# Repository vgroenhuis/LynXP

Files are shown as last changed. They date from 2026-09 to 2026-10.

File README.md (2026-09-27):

# LynXP

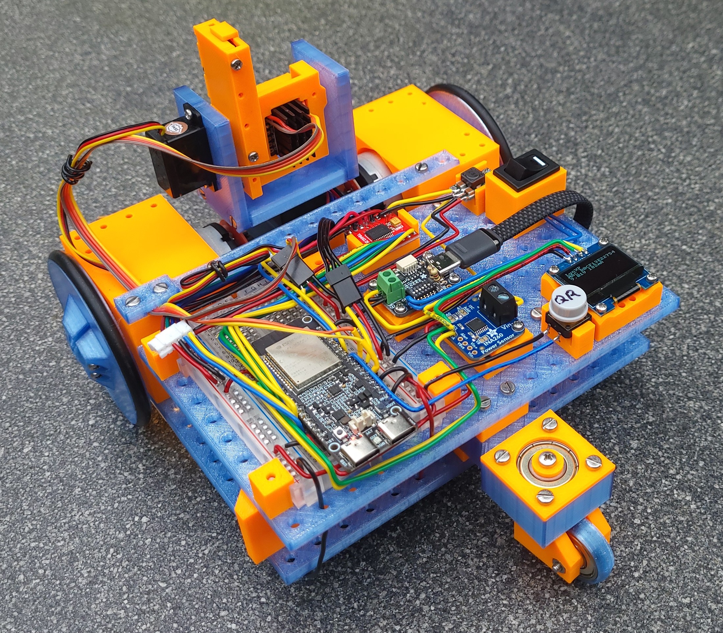
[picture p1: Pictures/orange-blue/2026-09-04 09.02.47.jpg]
LynXP


LynXP is a wheeled robot with pan-tilt camera and web-based control interface, through which minigames can be played. It is based on the SmartXP robot used in Creative Technology curriculum at University of Twente, hence the -XP in the name.

## Electronics

The power and control circuit (powerbank, USB power delivery trigger, current sensor, buck converter, ESP32-C5, ESP32-S3-Sense camera, motor driver, servos, motors, OLED, and status LED):

Power and control circuit diagram

Also available as [PDF](Schematic/powerbank_circuit.pdf) or [PNG](Schematic/powerbank_circuit.png).

A single PCB replacing the breadboard and modules is planned; see the [PCB requirements](Schematic/PCB_requirements.md).

## Bill of Materials

| Component | Part | Qty | Cost (each) | Supplier | Notes |
|---|---|---|---|---|---|
| Powerbank | Anker Zolo 10.000 mAh | 1 | €35 | [Anker](https://www.anker.com/products/a1688) / [GSMNetShop](https://gsmnetshop.nl/products/externe-batterij-anker-zolo-10000mah-30w-qc-plus-pd-1-x-usb-a-2-x-usb-c-zwart-a1688h11) / [DeBatterijPro](https://www.debatterijpro.nl/nl/product/anker-zolo-powerbank-10000mah-30w-qc-pluspd-met-usb-c-kabel-zwart.html) | Dimensions 110x65.5x25 mm. A different powerbank is possible; use the [CAD_Generators wall generator](https://github.com/vgroenhuis/CAD_Generators) to create a holder for other dimensions. |
| Drive motor | TT Motor GM37-520TB-1250-30-EN (12V, 30:1 transmission) | 2 | €10 | [Alibaba](https://www.alibaba.com/product-detail/TT-Motor-High-Torque-37mm-GM37_1601884925507.html) / [Aliexpress](https://nl.aliexpress.com/item/1005007677802607.html) / [Funduinoshop](https://funduinoshop.com/nl/doe-het-zelf-workshop/kits/chassis/jgb37-520-encoder-tandwielmotor-kit-12v-12rpm-met-wiel) / [TTmotor](https://www.ttmotor.com/high-torque-dc-gear-motor-589121520253040455580100120160750rpm-product/) | GM37 is a quite common geared DC motor size, but it is hard to find one in EU with encoder attached. |
| Camera module | Seeed XIAO ESP32S3 Sense | 1 | €16 | [Seeed Studio](https://www.seeedstudio.com/XIAO-ESP32S3-Sense-p-5639.html) / [TinyTronics](https://www.tinytronics.nl/en/development-boards/microcontroller-boards/with-wi-fi/seeed-studio-xiao-esp32-s3-sense) / [Reichelt](https://www.reichelt.com/nl/nl/shop/product/xiao_esp32s3_sense_wifi_bt_camera_ov3660_zonder_header-358353) |  |
| Main MCU | ESP32-C5-WIFI6-KIT-N16R8-M | 1 | €12 | [Aliexpress](https://nl.aliexpress.com/item/1005012275503208.html) | Compatible with ESP32-C5-DevkitC-1 from Espressif |
| USB-PD trigger board | HUSB238 | 1 | €11 | [Adafruit](https://www.adafruit.com/product/5991) / [Kiwi-electronics](https://www.kiwi-electronics.com/en/adafruit-usb-type-c-power-delivery-dummy-i2c-or-switchable-husb238-20162) | |
| Current sensor | INA260 | 1 | €11 | [Adafruit](https://www.adafruit.com/product/4226) / [Kiwi-electronics](https://www.kiwi-electronics.com/nl/adafruit-ina260-high-or-low-side-voltage-current-power-sensor-4222)  | Optional |
| Pan servo | MG996R 180° | 1 | €7 | [Bits&Parts](https://www.bitsandparts.nl/servo-motor-digitaal-mg996r-high-torque-metal-gears-p1922620) / [TinyTronics](https://www.tinytronics.nl/en/mechanics-and-actuators/motors/servomotors/mg996r-servo) / [Otronic](https://www.otronic.nl/nl/servo-mg996r-180-graden.html)  | LynXP One has SRT DL3020, which is overkill |
| OLED display | SSD1306, 128x64, 1.3" | 1 | €7 | [TinyTronics](https://www.tinytronics.nl/en/displays/oled/1.3-inch-oled-display-128*64-pixels-white-i2c) | LynXP One has 0.96", but this is too small |
| nOOds flexible LED | 30 cm | 1 | €5 | [Adafruit](https://www.adafruit.com/product/5509) / [Kiwi-electronics](https://www.kiwi-electronics.com/en/leds-114/other-leds-360/noods-flexible-led-filament-3v-300mm-long-warm-white-11360)  | Optional |
| Breadboard | EIC premium 400 points | 1 | €4 | [Tinytronics](https://www.tinytronics.nl/en/tools-and-mounting/prototyping-supplies/breadboards/eic-premium-breadboard-400-points-transparent) | |
| Motor driver | TB6612FNG | 1 | €3 | [Otronic](https://www.otronic.nl/nl/motor-driver-module-tb6612fng-voor-arduino.html) | |
| Tilt servo | SG90 180° | 1 | €3 | [Bits&Parts](https://www.bitsandparts.nl/servo-motor-analoog-micro-servo-9g-sg90-180%C2%B0-p1907205) / [TinyTronics](https://www.tinytronics.nl/en/mechanics-and-actuators/motors/servomotors/sg90-mini-servo) / [Otronics](https://www.otronic.nl/nl/servo-sg90-micro-180-graden.html) | Or MG90S. (LynXP One has Hitec HS-53) |
| Bearing | 608ZZ | 3 | €1 | [123-3D](https://www.123-3d.nl/123-3D-Kogellager-608ZZ-10-stuks-i1406.html) | For caster |
| Buck converter | OT253-B47 | 1 | €2 | [Otronic](https://www.otronic.nl/en/step-down-buck-converter-from-45v-24v-to-5v-3a-4r.html) | |
| O-ring | 60x5 mm | 2 | €1 | [Lagerkoning](https://www.lagerkoning.nl/o-ring-60x5mm-nbr-70.html) / [O-ring-stocks](https://www.o-ring-stocks.eu/nl/o-ring-60x5-nbr-nitril-70-shore-a-zwart-ors2856) | Inner diameter 60 mm, thickness 5 mm. Used as tyres for wheels. When mounted on rim, effective outer diameter is 71.5 mm. |
| On/off switch | 12x19 mm | 1 | €1 | [Tinytronics](https://www.tinytronics.nl/en/switches/manual-switches/rocker-switches/standaard-built-in-rocker-switch-small) | Optional; SPDT is better because switch closed = off |
| Pushbutton | 12 mm | 1 | €1 | [Kiwi-electronics](https://www.tinytronics.nl/en/switches/manual-switches/rocker-switches/standaard-built-in-rocker-switch-normal) | To show QR code on OLED; toggle switch also possible |
| **Total** | | | **€143** | | |

Total price excludes shipping costs, filament, wires, screws, resistors.

## CAD

Solidworks source files and STEP exports are available in [CAD/LynXP One Sept 2026](<CAD/LynXP One Sept 2026>):
- [Solidworks](<CAD/LynXP One Sept 2026/Solidworks>): native parts (`.SLDPRT`) and assemblies (`.SLDASM`), including [CompleteAssembly.SLDASM](<CAD/LynXP One Sept 2026/Solidworks/CompleteAssembly.SLDASM>)
- [STEP](<CAD/LynXP One Sept 2026/STEP>): neutral format for slicing and viewable in any CAD tool, including the [full robot assembly](<CAD/LynXP One Sept 2026/STEP/Full robot assembled/CompleteAssembly.STEP>)

The powerbank holder walls can be regenerated for different powerbank dimensions using [CAD_Generators](https://github.com/vgroenhuis/CAD_Generators).

## Assembly

Will be added later.

## Photos

More photos:
- [LynXP One](Pictures/orange-blue)
- [Older iterations](Pictures/older%20iterations)

## AI disclaimer
Claude was used to help developing software and circuit diagrams. No AI tools were used for hardware development.

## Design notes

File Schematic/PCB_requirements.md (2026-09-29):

# LynXP main PCB — requirements

This document lists the requirements for a single main PCB that replaces the breadboard, the
breakout modules and the wiring of LynXP One (see [powerbank_circuit.png](powerbank_circuit.png)
and the [BOM in the README](../README.md#bill-of-materials)). As many functions as practical
should be on the PCB itself instead of on plug-in modules.

Key words: **must** = hard requirement, **should** = strongly preferred, **may** = optional/nice to have.
Items marked *(verify)* are facts the designer must check against the current datasheet before
committing to the layout.

---

## 1. Scope: what moves onto the PCB

| Function | LynXP One (breadboard) | PCB |
|---|---|---|
| Main MCU | Waveshare ESP32-C5-WIFI6-KIT devkit | **ESP32-C5-WROOM-1U** module soldered on the PCB |
| USB-PD trigger | Adafruit HUSB238 breakout | **HUSB238** chip + USB-C receptacle on the PCB |
| Current/voltage sensor | Adafruit INA260 breakout | **INA260** chip on the PCB |
| 5 V buck converter | OT253-B47 module | Buck converter on the PCB |
| 3.3 V supply | Devkit LDO | Regulator on the PCB |
| Motor driver | TB6612FNG module | **TB6612FNG** chip on the PCB |
| Servo PWM | ESP32 LEDC | **PCA9685** 16-channel PWM driver (motor PWM stays on ESP32 LEDC) |
| Extra GPIO | — | **MCP23017** 16-bit I/O expander |
| Analog inputs | — | **8-channel I²C ADC** for add-on sensors (new, see §5.2) |
| Programming | Devkit USB | One USB-C port to the ESP32-C5 native USB (no USB-UART chip) |
| Camera (XIAO ESP32-S3 Sense) | Loose jumper wires | Keyed connector for a 4-wire flat cable |
| OLED display | 1.3" 128×64 I²C module on jumper wires | **1.3" 128×64 OLED integrated on the PCB** (strongly recommended; 4-pin header acceptable, see §5.1) |
| nOOds LED, buttons, power switch | Loose wires | Connectors / on-board parts |
| Headlights | — | Two headlight outputs with connectors (new, see §11.1) |
| Microphone, speaker | — | **Optional**: on-board I²S microphone and speaker amplifier (new, see §11.2) |

Stays off-board: powerbank, motors, servos, XIAO ESP32-S3 Sense camera, nOOds LED, headlights, optional speaker/mic.

---

## 2. Power input: USB-PD (HUSB238)

### 2.1 Negotiation
- **Must** have a USB-C receptacle (power only; CC1, CC2, VBUS, GND) for the powerbank; its VBUS net is named
  **VBUS_PD**. The connector is labelled
  **"POWER"** on the silkscreen, clearly different from the programming port.
- **Must** use the HUSB238 as PD sink controller. Default request: **12 V** (the GM37 motors are
  12 V motors; LynXP One ran them at 9 V).
- **Should** allow selecting the requested voltage (at least 9 V and 12 V; 5/15/20 V a bonus) with
  solder jumpers or a DIP switch on the HUSB238 voltage-select resistor network *(verify resistor
  values in the HUSB238 datasheet)*. The ISET/current resistor (10.5 kΩ on LynXP One) must also be
  on the board.
- **Must** connect the HUSB238 I²C (address 0x08) to the main I²C bus so firmware can read the
  contract and optionally request another PDO.
- The negotiated voltage is distributed as rail **V_BUS** (12 V by default). Its voltage depends on
  the selected/negotiated PDO (e.g. 9 V if the powerbank cannot deliver 12 V, or 15 V if selected).
  Everything on V_BUS must therefore work from 5 V up to 20 V.

### 2.2 On/off switch that wakes the powerbank (important)
Many powerbanks (including the Anker Zolo) switch their output off after a period of low current,
and only turn it on again when they detect a *new* attach event on the CC lines. Pulling and
re-inserting the cable works; switching the load does not.

- **Must**: the main on/off switch breaks the **CC1 and CC2** lines between the USB-C receptacle and
  the HUSB238 (one pole per CC line). Switching OFF looks like a cable unplug to the powerbank (it
  removes VBUS_PD itself); switching ON is a fresh attach, which wakes the powerbank.
- **Must**: the same switch also puts the **PD controller to sleep when OFF and wakes it when ON**,
  so that every switch-on starts the PD controller from its initial state and it renegotiates the
  contract, instead of keeping stale state alive on residual VBUS_PD/bulk-capacitor charge or on
  voltage back-fed from the programming USB port. Implement with an extra pole on the main switch,
  e.g. driving the PD controller's enable/sleep pin, or cutting its supply combined with a VBUS_PD
  discharge path so it gets a clean power-on reset *(verify which mechanism the HUSB238 supports;
  a comparable PD sink controller with a proper enable pin is acceptable if the HUSB238 has none)*.
- The main switch is therefore a multi-pole switch (e.g. 3PDT/4PDT slide or toggle). There must be
  only this one power switch for the PD input; no separate wake/sleep buttons.
  - Side effect: the switch carries only CC signal current, so no high-current switch is needed.
  - Keep CC traces short, place the switch close to the receptacle and the HUSB238. The switch
    must be a real mechanical switch, large and easy to reach from outside the robot (panel or
    edge mount, or wired to an off-board panel switch via a small connector with a footprint for
    an on-board switch as well).
- **Should** use another pole of the same main switch to also open the PD output load switch,
  so the output is guaranteed off even with a non-compliant source.
- Note: the powerbank must be connected with a **USB-C to USB-C** cable. A USB-A to C cable has
  no CC handshake and cannot be woken or switched this way.

### 2.3 Inrush and capacitance
- USB-C limits sink bulk capacitance on VBUS_PD before a contract is established (≤10 µF *(verify)*).
  Large bulk capacitors (motor/servo rails) **must** sit behind a load switch/PMOS that only closes
  once the HUSB238 reports a valid contract (as the Adafruit breakout does), with soft-start.

### 2.4 Protection
- **Must**: TVS diode on VBUS_PD rated for the maximum selectable PD voltage (≥ 20 V standoff if 20 V
  can be selected).
- No fuse on the PCB: overcurrent protection is provided by the powerbank, which cuts its output
  when the negotiated current (~2.5–3 A at 12 V for a 30 W powerbank) is exceeded.

### 2.5 Current sensing (INA260)
- **Must** place an INA260 (integrated shunt, high-side) in series with V_BUS directly after
  the PD output switch, so it measures the complete robot consumption.
- I²C address: **0x40** (firmware `INA260_I2C_ADDR`), A0 and A1 hardwired to GND.
- ALERT pin left unconnected.

---

## 3. Power rails

| Rail | Source | Minimum rating | Notes |
|---|---|---|---|
| **V_BUS** (12 V default; VBUS_PD after PD load switch and INA260) | HUSB238 | 3 A | Motors (TB6612 VM), buck inputs, exposed |
| **5 V** logic | Buck from V_BUS | 3 A | Camera, nOOds, exposed |
| **V_SERVO** (5 V default) | Separate buck from V_BUS | 3 A | 8 servo headers |
| **3.3 V** | Regulator from 5 V | 1 A | ESP32-C5, MCP23017, PCA9685, INA260, HUSB238 I/O, encoders |

- Net names: **VBUS_PD** = raw VBUS pin of the POWER connector; **VBUS_PROG** = raw VBUS pin of
  the PROG connector; **V_BUS** = main rail (VBUS_PD after load switch and INA260). Bare
  "VBUS" is not used as a net name.
- Bucks **must** accept 5–20 V input with margin (≥ 28 V abs. max) because the rail follows the PD
  voltage.
- Servos **should** get their own buck, separate from logic 5 V, so servo stall currents
  (MG996R ~2.5 A stall) cannot brown out the ESP32. Bulk capacitance on V_SERVO (≥ 470–1000 µF,
  low-ESR).
- 3.3 V regulator must handle ESP32-C5 Wi-Fi peaks (≥ 500 mA peak for the module alone); an LDO
  from 5 V with ≥ 1 A rating or a small buck.
- When only the programming USB port is connected, the 5 V/3.3 V logic **must** run from **VBUS_PROG** (the
  programming port's VBUS)
  through an ORing diode / ideal diode, without back-feeding into the buck output or the PD side.
  V_SERVO and V_BUS stay unpowered in that case.
- **Must**: power-good LED on each rail (V_BUS, 5 V, V_SERVO, 3.3 V).
- **Should**: test points on every rail and GND.

### 3.1 Exposed power
- **Must** expose **all rails — V_BUS, V_SERVO, 5 V, 3.3 V — and GND**, so they can feed
  additional external components, both on:
  - **screw terminals** (5.0 mm or 3.5 mm pitch, one terminal per rail + at least two GND), and
  - **2.54 mm female headers** (several pins per rail, e.g. a 2×N or 4×1 block per rail).
- Silkscreen voltage next to every pin. Use distinct connector colours or clear markings to avoid
  plugging a 3.3 V device into V_BUS. Silkscreen names V_BUS and V_SERVO with their
  default voltage (e.g. "V_BUS (12 V)").

---

## 4. Main MCU: ESP32-C5-WROOM-1U

- **Must** use ESP32-C5-**WROOM-1U**, the variant with an antenna connector (U.FL/IPEX) for an
  external antenna. The WROOM-1 variant with PCB antenna is not acceptable. A variant **with PSRAM is required**
  (current devkit is N16R8); choose flash/PSRAM size to match the firmware partition table
  ([partitions.csv](../Firmware/Robot_ESP32_C5_IDF/partitions.csv)) *(verify availability)*.
- **Must** route the U.FL cable to an external antenna mounting point away from motors, the metal
  frame and the powerbank; keep the module away from the buck converters and motor traces.
  A 2.4/5 GHz dual-band external antenna with U.FL cable is part of the BOM.
- **Must**: EN reset button, BOOT button on GPIO28, EN RC delay
  (10 kΩ / 1 µF), decoupling per module datasheet.
- Reserved pins (from [board_pins.hpp](../Firmware/Robot_ESP32_C5_IDF/main/board_pins.hpp)):
  GPIO13/14 = USB D−/D+, GPIO16–22 = flash/PSRAM, **GPIO15 cannot be used** (PSRAM).
- Strapping: **GPIO28 must not be externally driven** — only the BOOT button may pull it low. It
  may only connect to inputs (as the camera UART RX line in the pin map below). The other
  strapping pins need no special care.

### 4.1 Programming port
- **Must**: exactly one USB-C receptacle, labelled **"PROG"**, wired to the ESP32-C5 native
  USB-Serial/JTAG (GPIO13/14). No USB-UART converter chip. 5.1 kΩ Rd on its own CC1/CC2, ESD
  protection on D+/D− (e.g. USBLC6-2), 90 Ω differential routing.
- **Must**: a 2.54 mm UART0 header for an external USB-UART adapter: GND, U0TXD, U0RXD
  (GPIO11/GPIO12 *(verify)*), plus EN and BOOT so an adapter can also flash the module. 3.3 V pin
  via solder jumper, open by default.

### 4.2 Suggested pin map
Pan/tilt servos move to the PCA9685 and motor direction pins to the MCP23017 (see §6, §7). Motor
PWM stays on native ESP32 pins (LEDC, 20–30 kHz, inaudible) on the same GPIOs as now; the remaining ESP32 pins keep the bench-verified LynXP One assignment. The designer may
reassign pins; any change must be documented so `board_pins.hpp` can be updated.

| Function | Connection |
|---|---|
| Motor PWMA (right) / PWMB (left) | 9 / 0 (LEDC; pull-downs so motors are off until firmware runs) |
| Motor AIN1, AIN2 (right) / BIN1, BIN2 (left) | MCP23017 GPA0, GPA1 / GPA2, GPA3 |
| Pan / tilt servo | PCA9685 channel 0 / 1 |
| Encoder left A, B | 26, 25 |
| Encoder right A, B | 24, 23 |
| I²C SDA / SCL | 2 / 3 |
| Camera UART RX / TX | 4 / 28 |
| Screen-select potentiometer (§5.1) | GPIO1 (ADC1_CH0) |
| UART0 TX / RX | 11 / 12 *(verify)* |
| I²S BCLK / WS (optional microphone and amplifier, §11.2) | 5 / 6 |
| I²S DIN (microphone) / DOUT (amplifier) | 8 / 10 |
| Addressable status LED + RGB LED strip header (§11) | 7 |

Any GPIOs left over (e.g. GPIO27, formerly the QR button) go to a 2.54 mm female header.

Encoders **must** stay on native GPIOs (PCNT peripheral).

---

## 5. I²C bus

- One 3.3 V I²C bus shared by all devices, running at 400 kHz.
- **Must**: external SDA/SCL pull-up resistors to 3.3 V, populated by default (0805, e.g. 2.2 kΩ;
  value chosen for the total bus capacitance at 400 kHz). The ESP32-C5's internal pull-ups are not
  relied on.
- Address map (must be conflict-free — note the PCA9685 default **0x40 clashes with the INA260**):

| Device | Address |
|---|---|
| HUSB238 | 0x08 (fixed) |
| MCP23017 | 0x20 (A0–A2 solder jumpers) |
| OLED (SH1106/SSD1306-compatible) | 0x3C (0x3D via solder jumper) |
| INA260 | 0x40 (A0, A1 to GND) |
| PCA9685 | **0x41** (A0 to 3.3 V, A1–A5 to GND); its All-Call address 0x70 is also in use |
| 8-channel ADC (§5.2) | 0x48 (address pins to GND) |
| Board-ID EEPROM (§12.1) | 0x50 |

- **Should**: one or two Qwiic/STEMMA QT (JST-SH 4-pin, 3.3 V) connectors plus a 2.54 mm I²C
  header for add-ons.

### 5.1 On-board 1.3" OLED display
- **Strongly recommended**: the 1.3" 128×64 monochrome OLED is integrated on the PCB. Use a bare
  1.3" OLED glass panel with integrated controller and FPC tail (typically 30-pin, soldered or in
  an FPC connector), with all support circuitry on the PCB. Panel colour white (as on LynXP One);
  blue or yellow acceptable.
- Controller: the current firmware uses the SSD1306 driver with a 2-column offset
  (`CONFIG_OFFSETX=2` in [sdkconfig.defaults](../Firmware/Robot_ESP32_C5_IDF/sdkconfig.defaults)),
  i.e. the LynXP One module is effectively an **SH1106** (132-column RAM). An SH1106 panel is
  preferred so firmware stays unchanged; an SSD1306/SSD1309 panel is acceptable if documented.
  *(verify controller of the chosen panel)*
- Interface: **I²C** on the shared bus, address 0x3C (0x3D selectable). Interface-select pins
  (BS0–BS2) strapped for I²C, D1/D2 joined for SDA as the panel datasheet specifies.
- Supply: logic from 3.3 V. The OLED drive voltage (VCC/VPP, typically 7–15 V) must be generated
  as required by the controller: internal charge pump with its flying capacitors (SH1106/SSD1306),
  or a small external boost converter if the panel needs external VCC (e.g. SSD1309). Include
  IREF resistor, VCOMH/VCC decoupling and all other passives from the panel's reference circuit.
- RES# (reset) connected to an MCP23017 output or ESP32 GPIO with RC fallback, so firmware can
  reset a hung display.
- **Should**: the display power can be switched off (load switch or controller sleep is enough).
- Mechanical: the panel **must** be on the top side, fully visible with the robot assembled,
  readable in the orientation the robot is normally viewed from (text upright). Provide a cut-out
  or keep-out under the FPC bend, and a mounting method for the glass (double-sided foam tape
  area and/or a 3D-printed bezel with M2/M2.5 holes; include the bezel in the STEP deliverable).
  Keep tall components and connectors away from the panel so it is not damaged or shadowed.
- **Must**: a **potentiometer with turn knob directly right of the OLED**, used to select the screen
  shown. PCB-mount rotary
  potentiometer with shaft (e.g. 9 mm type, linear, 10 kΩ) and a knob large enough to turn by
  hand, between 3.3 V and GND, wiper to a native ESP32-C5 ADC pin with a 100 nF filter capacitor.
  The knob must be reachable with the robot assembled and not obstruct the view of the display.
- **Acceptable alternative** (only if integrating the panel is not feasible): a 4-pin 2.54 mm
  female header on the same I²C bus for a 1.3" OLED module, placed and with mounting holes so the
  module sits in the same position (display visible, potentiometer right of it). Note that the
  order of the 4 pins differs per manufacturer (e.g. GND-VCC-SCL-SDA vs VCC-GND-SCL-SDA), so the
  header needs solder jumpers for both common orders — one reason integration is strongly
  preferred. The on-panel requirements above (controller, charge pump, RES#) then do not apply.

### 5.2 8-channel ADC for analog sensors
Lets students add analog sensors (potentiometers, light sensors, IR distance sensors, line
sensors, etc.) without using ESP32 pins.
- **Must**: an 8-channel I²C ADC on the shared bus, ≥ 10-bit, e.g. **ADS7828** (12-bit, 8
  single-ended inputs, I²C 0x48–0x4B) or an equivalent available at JLCPCB/LCSC. Powered from 3.3 V;
  input range 0–3.3 V (reference = 3.3 V supply, or internal reference if the chosen part has a
  better one — document which).
- **Must**: **8 sensor connectors**, one per channel: 3-pin 2.54 mm male headers in the order
  **GND, 3.3 V, signal** (same style as the servo headers, so standard 3-wire sensor cables fit),
  labelled **A0–A7**, each with label space for the sensor name.
- Supply on these headers is 3.3 V only, so sensor outputs stay within the ADC range. No 5 V
  option; users with 5 V-only sensors add their own level shifting.
- Input protection per channel: series resistor (~1 kΩ) and clamping to 3.3 V/GND, plus footprints
  (unpopulated by default) for a pull-down resistor and an RC filter capacitor.

---

## 6. PCA9685 PWM driver: servos, headlights, LEDs

- **Must**: PCA9685 powered from 3.3 V (3.3 V signal levels are fine for hobby servos).
- **Must**: OE pin pulled **high** (outputs disabled) by default and controlled by MCP23017 **GPA7**
  (output-only pin; floats at reset so the pull-up keeps OE high), so servos receive no pulses
  until firmware has initialised them. This also prevents
  the random boot-time pan rotation seen on LynXP One.
- All 16 PCA9685 channels share one PWM frequency (~50 Hz for servos; the PCA9685 cannot exceed
  ~1.5 kHz), which is why motor PWM is not on the PCA9685.
- **Must**: **8 servo headers**, standard 3-pin 2.54 mm male (GND, V_SERVO, signal — in that
  order, with polarity marked on silkscreen), on PCA9685 channels 0–7:
  - channel 0 = **PAN**, channel 1 = **TILT**, channels 2–7 = **SPARE 1–6** (label space).
  - Series resistor (~220 Ω) on each signal line.
  - Spacing wide enough to plug in 8 servo connectors side by side.
- Channels 11 and 12: left and right **headlights** (§11.1).
- **Must**: break out PCA9685 channels 8, 9 and 13–15 on a 2.54 mm female header (with GND and 5 V next to it).
- **Should**: channel 10 drives a logic-level low-side MOSFET for the **nOOds LED** (dimmable),
  with footprint for the series resistor (47 Ω on LynXP One) and a 2-pin connector.

---

## 7. MCP23017 GPIO expander

- **Must**: MCP23017 at 3.3 V, RESET pulled up (optionally to a GPIO), INTA/INTB not
  connected (firmware polls the inputs).
- **Note** *(verify)*: newer MCP23017 datasheets specify **GPA7 and GPB7 as output-only**. Use these
  two pins for outputs (e.g. LEDs) and not for switches.
- Suggested allocation:
  - GPA0–GPA3: TB6612FNG AIN1, AIN2, BIN1, BIN2 (outputs). Pull-downs on these four lines so both
    motors are stopped while the MCP23017 is in reset or not yet configured.
  - 4-position DIP switch (inputs, see §9).
  - 4 large user buttons (inputs).
  - GPA7: PCA9685 OE (output, §6).
  - GPB7: speaker amplifier shutdown/mute (output, §11.2).
  - User LEDs (as needed).
  - All unused pins on a labelled 2.54 mm female header with GND and 3.3 V.

---

## 8. Motors

### 8.1 Driver
- **Must**: TB6612FNG on the PCB, VM = V_BUS, VCC = 3.3 V, STBY pulled up to 3.3 V (always
  enabled, as the current firmware assumes; no switch).
- Channel A = RIGHT motor, channel B = LEFT motor (matches firmware).
- Generous copper and thermal vias for the TB6612FNG (1.2 A continuous / 3.2 A peak per channel).
  GM37-520 stall current at 12 V should be checked against this *(verify)*; if it is too high, a
  pin-compatible-in-function alternative with IN1/IN2/PWM control may be proposed.
- Bulk capacitor (≥ 100 µF) and 100 nF at VM.

### 8.2 Motor connectors (per motor, both motors)
All three options on the board, electrically in parallel (only one used at a time):
1. **6-pin 2.0 mm pitch socket** matching the GM37-520 encoder motor cable (JST-PH-style).
   Signals: M+, M−, encoder VCC, encoder GND, encoder A, encoder B. Pin order **must** be checked
   against the actual TT Motor GM37-520TB-1250-30-EN cable *(verify)*; silkscreen the pin names.
2. **2.54 mm female header** (6-pin, same signals).
3. **2-pin screw terminal** for M+/M− only (motors without encoder, or thick wires).

### 8.3 Encoders
- Encoder VCC is **3.3 V**, so A/B connect directly to the ESP32 GPIOs (no selector jumper, no
  level limiting).
- Footprints for pull-ups and small RC filters (DNP by default) on each A/B line.
- Encoder spec (for reference): 12 PPR, 30:1 gearbox.

---

## 9. Switches, buttons and labels

- **Main power switch** (large, see §2.2): multi-pole, breaking CC1/CC2 and sleeping/waking the PD
  controller. No other power or enable switches (no motor-enable or servo-power switch), to avoid
  a switch being forgotten in the wrong state.
- **Must**: **4 large user buttons** (e.g. 12 mm tactile buttons with caps) on native GPIO or
  MCP23017, free for firmware/minigame use. There is no
  dedicated QR button any more; screen selection (including the QR code) is done with the
  potentiometer next to the OLED (§5.1).
- **Must**: at least one **4-position DIP switch** on the MCP23017 (e.g. robot ID, mode flags).
- **Must**: **space for labels** next to every user button, DIP position, spare servo, spare
  header and exposed rail: white solder-mask/silkscreen fields that can be written on with a
  permanent marker, large enough for a short word.
- Reset (EN) and BOOT buttons (small is fine).

---

## 10. Camera (XIAO ESP32-S3 Sense)

- The camera sits on the pan-tilt head. A **4-wire flat cable** is soldered to the XIAO and ends in
  a connector that plugs into the PCB.
- **Must**: keyed, latching/friction-locked 4-pin connector on the PCB (e.g. JST-PH 2.0 mm or
  JST-XH 2.5 mm; the designer selects one and specifies the mating cable connector).
  Pinout:

| Pin | Signal | XIAO side | ESP32-C5 side |
|---|---|---|---|
| 1 | 5 V | 5V pad | 5 V rail |
| 2 | GND | GND | GND |
| 3 | CAM_TX | D0 (GPIO1, TX) | GPIO4 (UART1 RX) |
| 4 | CAM_RX | D1 (GPIO2, RX) | GPIO28 (UART1 TX) |

- 3.3 V levels. Small series resistors (e.g. 100–330 Ω) on the UART lines.
- Place the connector so the cable has room to follow the pan/tilt motion; provide a strain-relief
  point (hole for a cable tie) next to it.
- Budget ≥ 500 mA on the 5 V rail for the camera.
- Protect against back-feeding when the XIAO's own USB is plugged in for programming *(verify
  whether the XIAO already has a diode on its 5 V pin)*.

---

## 11. Other connectors and indicators

- Addressable status LED (WS2812/SK6812) on GPIO7.
- **Must**: **3-pin header for an addressable RGB LED strip** (WS2812/SK6812), pins **5 V, DATA,
  GND** (silkscreen order and arrow for data direction), e.g. JST-XH 2.5 mm or 2.54 mm header.
  - DATA is the continuation of the on-board status LED chain (status LED DOUT → strip DIN), so
    no extra GPIO is needed; the strip LEDs follow the status LED in the chain.
  - GPIO7 is level-shifted from 3.3 V to 5 V (e.g. 74AHCT1G125) before the status LED, which runs
    from 5 V; its DOUT then drives the strip at 5 V levels. ~330 Ω series resistor on DATA at the
    header; bulk capacitor (≥ 100 µF) on 5 V at the header.
  - Powered from the 5 V rail; strip length is limited by the 5 V budget (§3), to be noted on the
    silkscreen or in the documentation.
- nOOds LED 2-pin connector (see §6).
- Female header breakout of all free ESP32 GPIOs, MCP23017 spare pins and PCA9685 channels 8, 9 and 13–15,
  each group with GND and supply pins next to it.
- All connectors labelled on the silkscreen with signal name and voltage.

### 11.1 Headlights
- **Must**: two headlight outputs (LEFT, RIGHT), each a 2-pin connector (JST-PH 2.0 mm) for an
  off-board white LED mounted at the front of the robot.
- Each driven by a logic-level low-side MOSFET from PCA9685 channel 11/12 (dimmable), from the 5 V
  rail, up to 350 mA per output.
- Footprint for a current-limiting resistor per output (size for ≥ 1 W), so both small 5 mm LEDs and
  1 W power LEDs can be used. A small constant-current LED driver instead of the resistor is
  acceptable.

### 11.2 Microphone and speaker (optional)
Microphone and speaker are optional; include them if board space allows. If left out, the I²S
pins in §4.2 become free GPIOs. If included, the following applies:
- On-board **I²S MEMS microphone** (e.g. ICS-43434 or INMP441-compatible, available at
  JLCPCB/LCSC), top-port so it fits single-sided assembly. Placed at a board edge, away from the
  motor driver, bucks and speaker connector; keep the sound port free (no silkscreen/solder mask
  over it, no parts on top of it).
- **I²S class-D amplifier** (e.g. MAX98357A) powered from the 5 V rail, driving a
  2-pin speaker connector (JST-PH 2.0 mm) for an off-board 4–8 Ω, 1–3 W speaker. Shutdown/mute
  pin to MCP23017 GPB7 (pulled to shutdown by default so the speaker is silent during boot).
- Microphone and amplifier share I²S BCLK and WS; separate data lines (see §4.2). Pin choice must
  match the ESP32-C5 I²S peripheral *(verify)*.
- Decouple the amplifier supply well (≥ 10 µF + 100 nF close to the chip) and route the speaker
  output as a short differential pair away from the microphone and the antenna cable.

---

## 12. Mechanical and manufacturing

- Board outline and mounting holes **must** fit the LynXP frame in place of the breadboard and
  module holders (see the CAD in [CAD/LynXP One Sept 2026](<../CAD/LynXP One Sept 2026>),
  e.g. `Frame_16x10` and `BreadboardHolder_Clamp`).
- **Must**: board size at most **160 × 100 mm**; smaller (e.g. **100 × 100 mm**) preferred.
- **Must**: **single-sided assembly**: all SMD parts on the top side. The bottom side carries only
  through-hole solder joints.
- **Must**: mounting holes **3.2 mm** diameter (M3), positioned on a **10 mm grid** so they line up
  with the frame. Isolated from GND or GND-connected by solder jumper.
- **Must**: the PCB can be screwed onto the robot without separate standoff parts. Each mounting
  hole gets a standoff cylinder of the correct height (clearing the through-hole pins on the
  bottom side) as part of the 3D-printed frame/mount, delivered as CAD (Solidworks + STEP)
  together with the PCB.
- USB-C ports, main power switch, large user buttons and DIP switch reachable with the robot
  assembled (board edge / top side). The POWER port faces the powerbank.
- The on-board OLED visible and the camera connector placed so the cable reaches the pan-tilt head.
- A 3D model (STEP) of the assembled PCB must be delivered for integration in the Solidworks
  assembly.
- **Must**: **four-layer** board. Solid ground plane; separate high-current
  (motor/servo) return paths from logic ground and join them near the power input.
- **Must**: manufactured and assembled by JLCPCB; all parts available from JLCPCB/LCSC.
  Through-hole connectors and switches may be hand-soldered.
- **Must**: the design passes a check with JLCPCB's **JLCDFM** tool before ordering; the DFM report
  is part of the deliverables. Passive size ≥ 0603 (0805 preferred) for hand rework.
- Silkscreen: project name, board revision, date, polarity marks, pin-1 marks, rail voltages.

### 12.1 Board identification
- **Must**: firmware must be able to determine that it runs on this PCB instead of the
  breadboard + loose wires setup (the two have different pin maps), and which board revision.
- Implement with a small I²C EEPROM (e.g. 24C02, address 0x50, write-protect enabled after
  programming) holding board name and revision. The presence of the PCA9685 at 0x41 and the
  MCP23017 at 0x20 (neither exists on the breadboard) serves as a secondary check.

---

## 13. Deliverables

- **Must**: designed in **KiCad**; the KiCad project (schematic, PCB layout, custom symbols,
  footprints and 3D models) committed to the LynXP repository (e.g. a `PCB/` folder).
- Schematic PDF, Gerbers, pick-and-place (CPL) file, STEP model, JLCDFM report.
- BOM listing for every part the **JLCPCB/LCSC part number** (Cxxxxx), plus manufacturer part number.
- Pin map table (ESP32 GPIO, MCP23017 pin, PCA9685 channel per function) so
  [board_pins.hpp](../Firmware/Robot_ESP32_C5_IDF/main/board_pins.hpp) can be updated.
- Updated power/control diagram replacing [powerbank_circuit.png](powerbank_circuit.png).

## 14. Firmware impact (for information)

The following firmware changes follow from this board and are not part of the PCB design:
PCA9685 driver for servos, headlights and nOOds (OE via MCP23017), MCP23017 driver for motor direction,
DIP switch/buttons/LEDs, headlights, I²S microphone and speaker, ADC driver for the analog inputs, screen selection with the
potentiometer (replaces the QR button), motor direction changes over I²C (only on reversal; PWM stays on LEDC), PD voltage
handling at 12 V instead of 9 V (motor PWM limits), board detection at startup (§12.1) with
the breadboard or PCB pin map selected accordingly, and any pin reassignments.

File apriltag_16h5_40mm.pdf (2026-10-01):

AprilTag family tag16h5 -- tag size 40 mm (outer black border), cell 6.67 mm | page 1/2 -- print at 100% (no 'fit to page')
ID 0 | ID 1 | ID 2 | ID 3
ID 4 | ID 5 | ID 6 | ID 7
ID 8 | ID 9 | ID 10 | ID 11
ID 12 | ID 13 | ID 14 | ID 15
ID 16 | ID 17 | ID 18 | ID 19

100 mm -- check after printing

AprilTag family tag16h5 -- tag size 40 mm (outer black border), cell 6.67 mm | page 2/2 -- print at 100% (no 'fit to page')
ID 20 | ID 21 | ID 22 | ID 23
ID 24 | ID 25 | ID 26 | ID 27
ID 28 | ID 29

100 mm -- check after printing

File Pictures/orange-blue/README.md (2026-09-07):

# LynXP One, developed in summer 2026

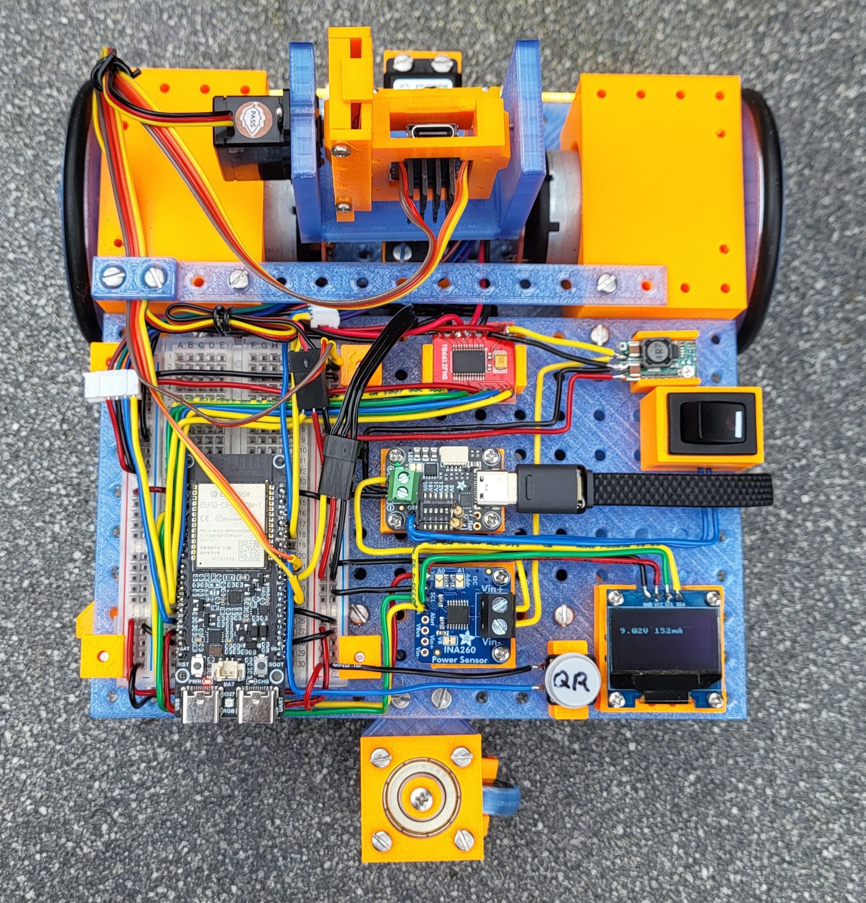
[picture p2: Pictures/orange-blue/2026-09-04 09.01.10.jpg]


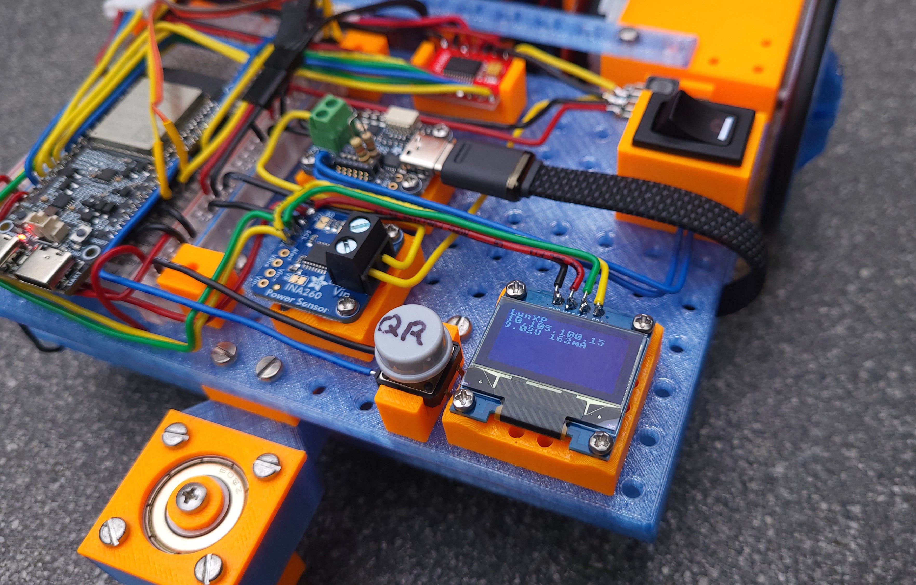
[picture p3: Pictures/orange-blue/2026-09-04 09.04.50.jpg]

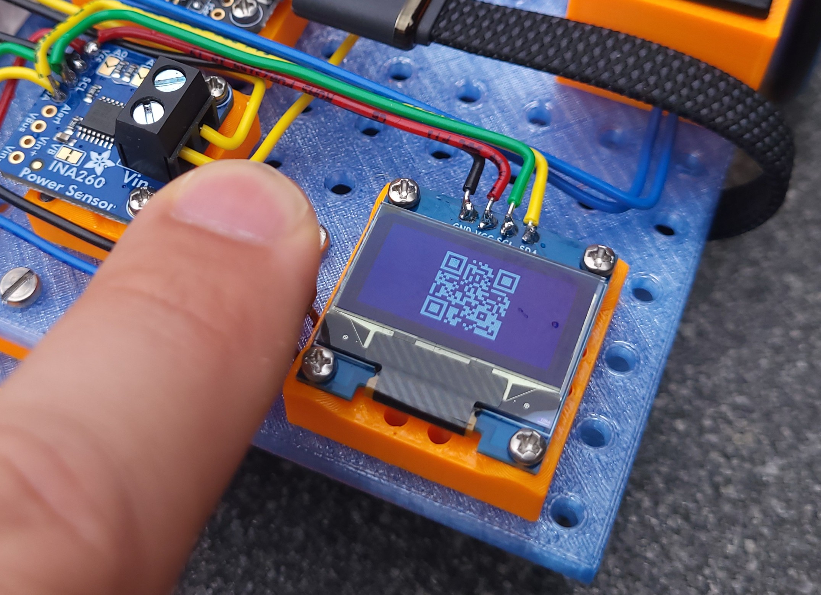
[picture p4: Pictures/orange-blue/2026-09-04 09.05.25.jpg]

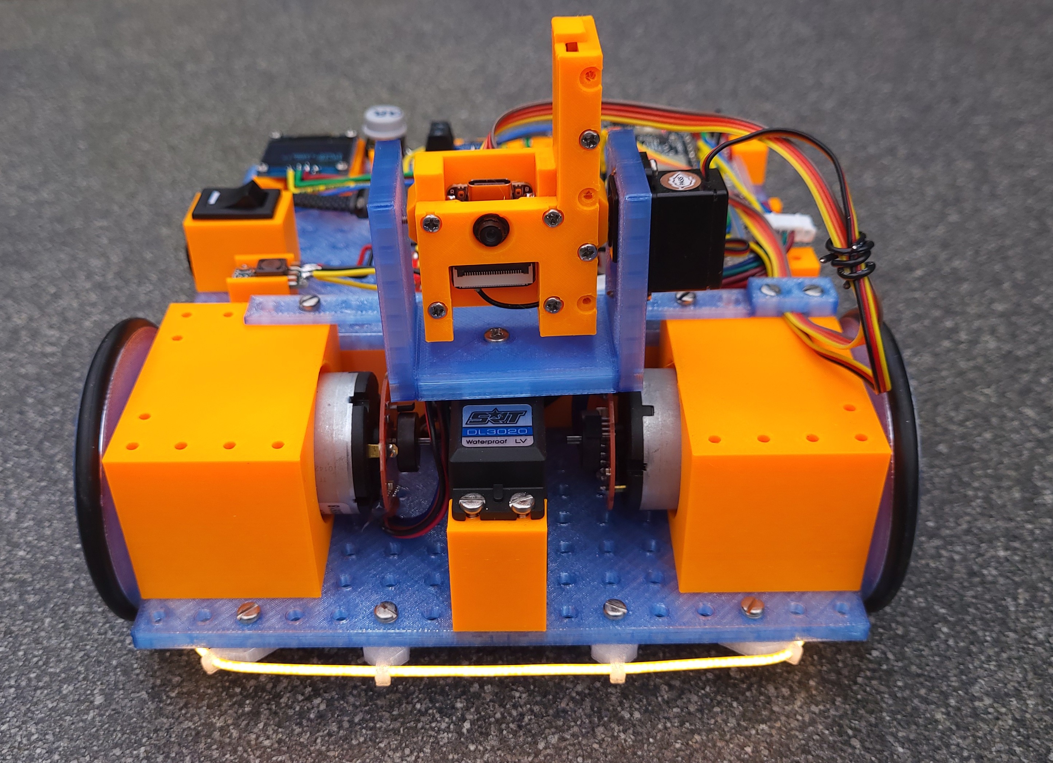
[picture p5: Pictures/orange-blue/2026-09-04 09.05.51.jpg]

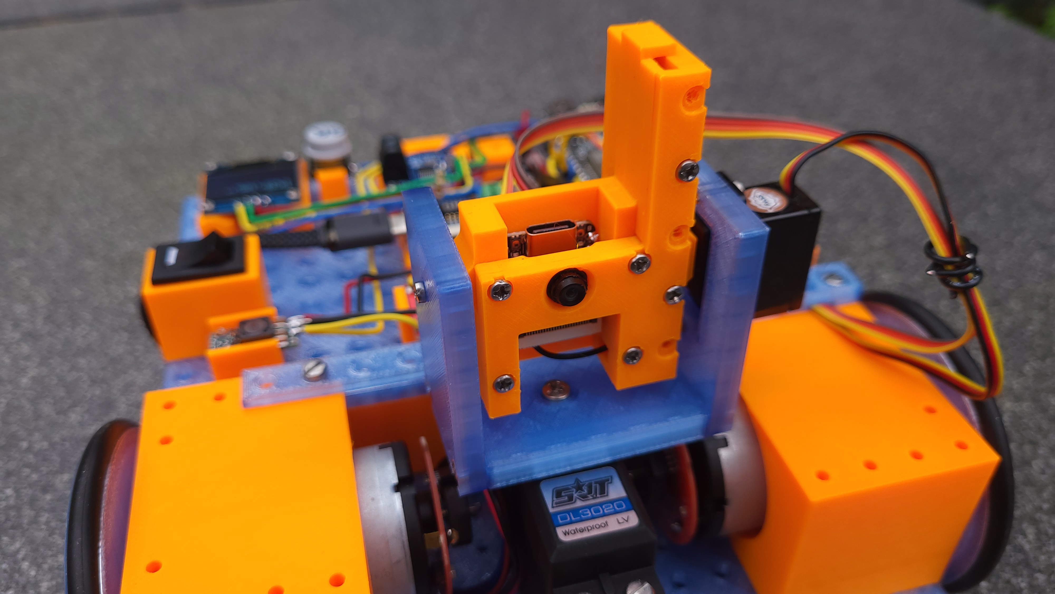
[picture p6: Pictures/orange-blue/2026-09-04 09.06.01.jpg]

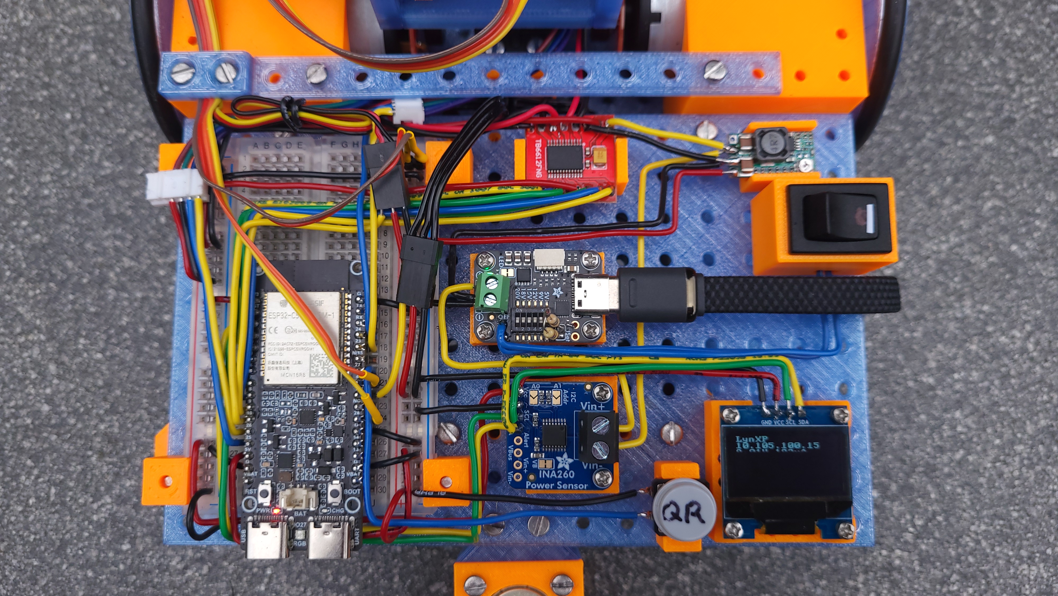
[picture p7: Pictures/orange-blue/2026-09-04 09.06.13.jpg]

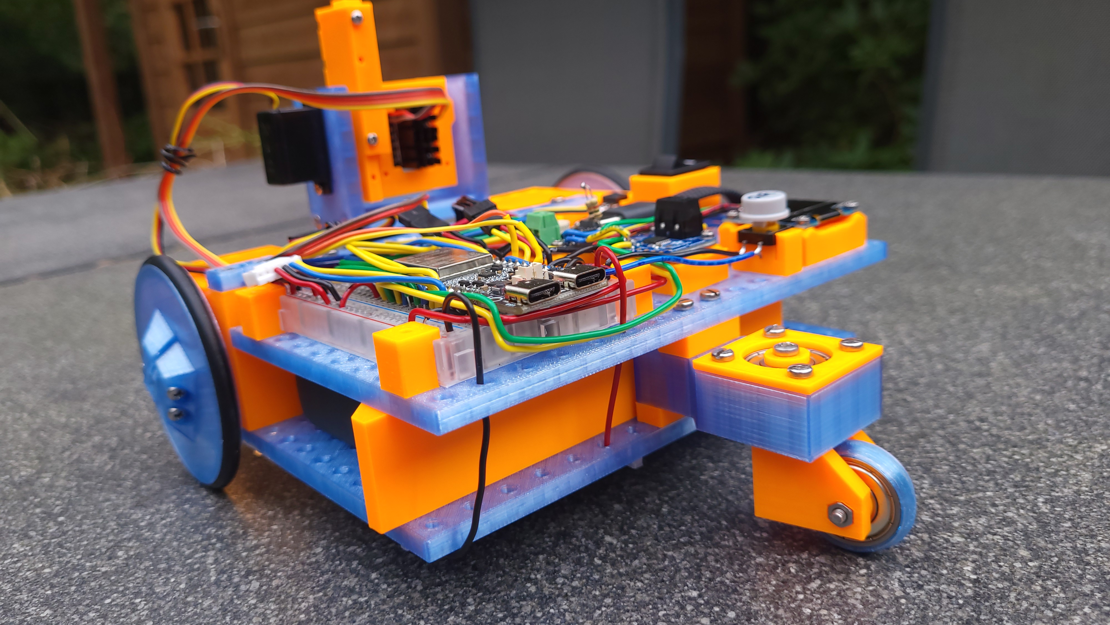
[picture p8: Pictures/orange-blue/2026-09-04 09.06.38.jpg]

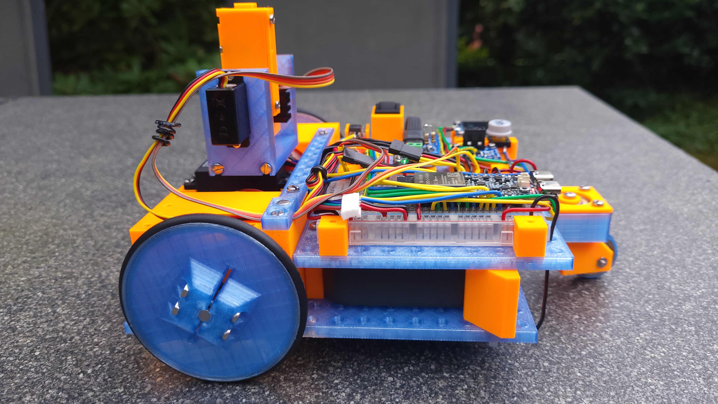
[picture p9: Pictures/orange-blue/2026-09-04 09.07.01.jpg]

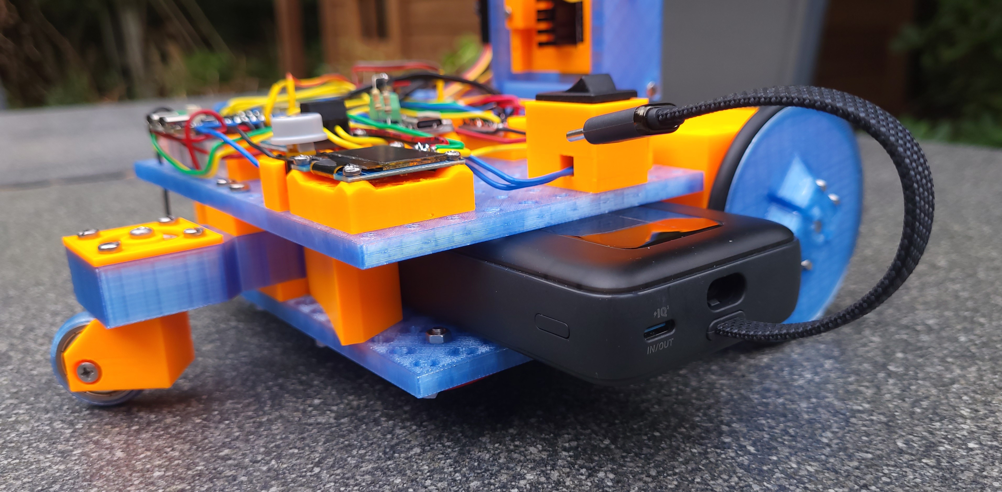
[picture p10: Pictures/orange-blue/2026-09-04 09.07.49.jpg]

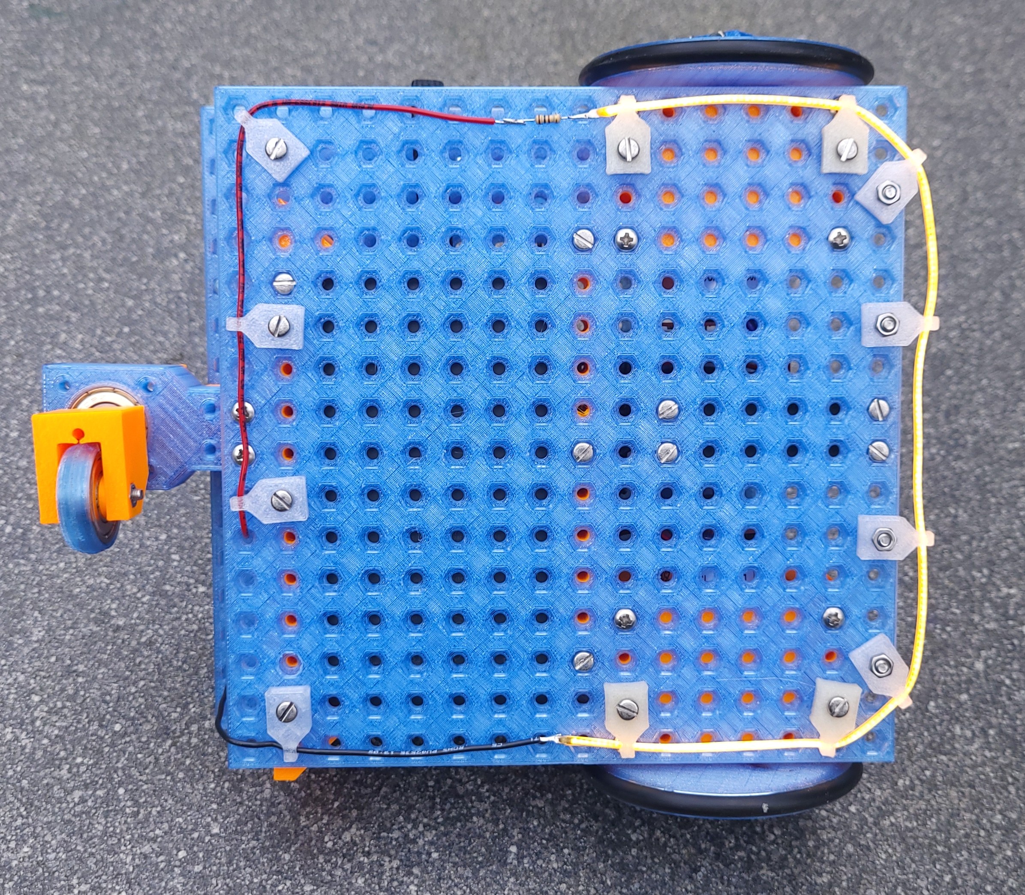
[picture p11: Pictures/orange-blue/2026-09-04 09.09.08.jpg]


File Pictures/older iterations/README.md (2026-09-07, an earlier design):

# Older iterations

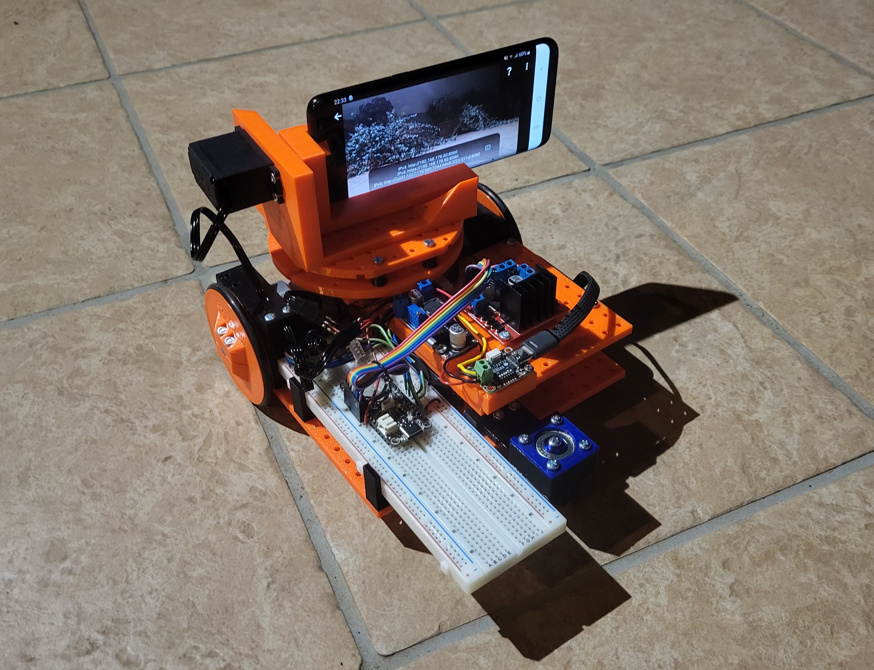
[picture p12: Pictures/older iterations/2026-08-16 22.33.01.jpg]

Initially I used an old mobile phone as webcam. But it had several drawbacks: large size, high power consumption, needs to be started manually, etc.

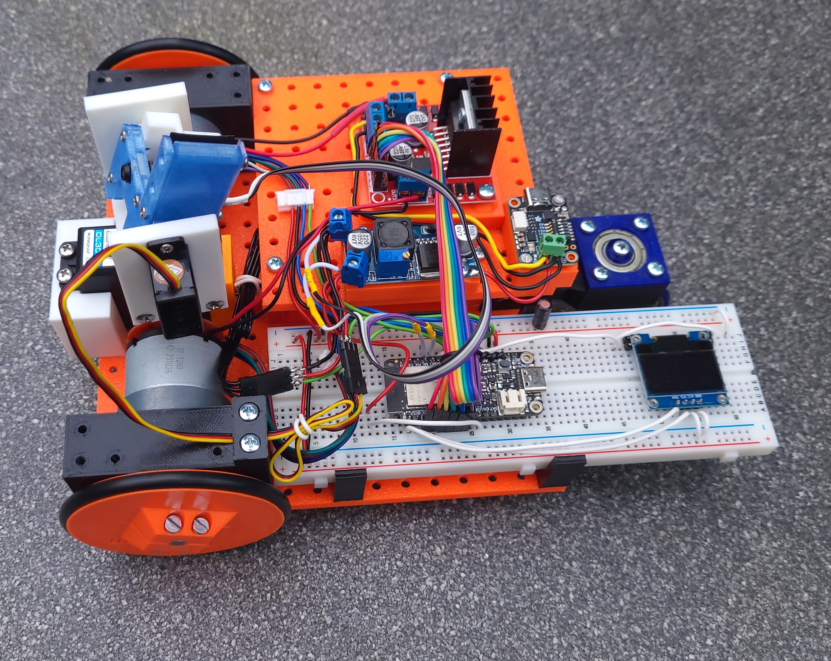
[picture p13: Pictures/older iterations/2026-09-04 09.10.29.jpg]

A L298N was used as H-bridge, and an ESP32-S3 as microcontroller.

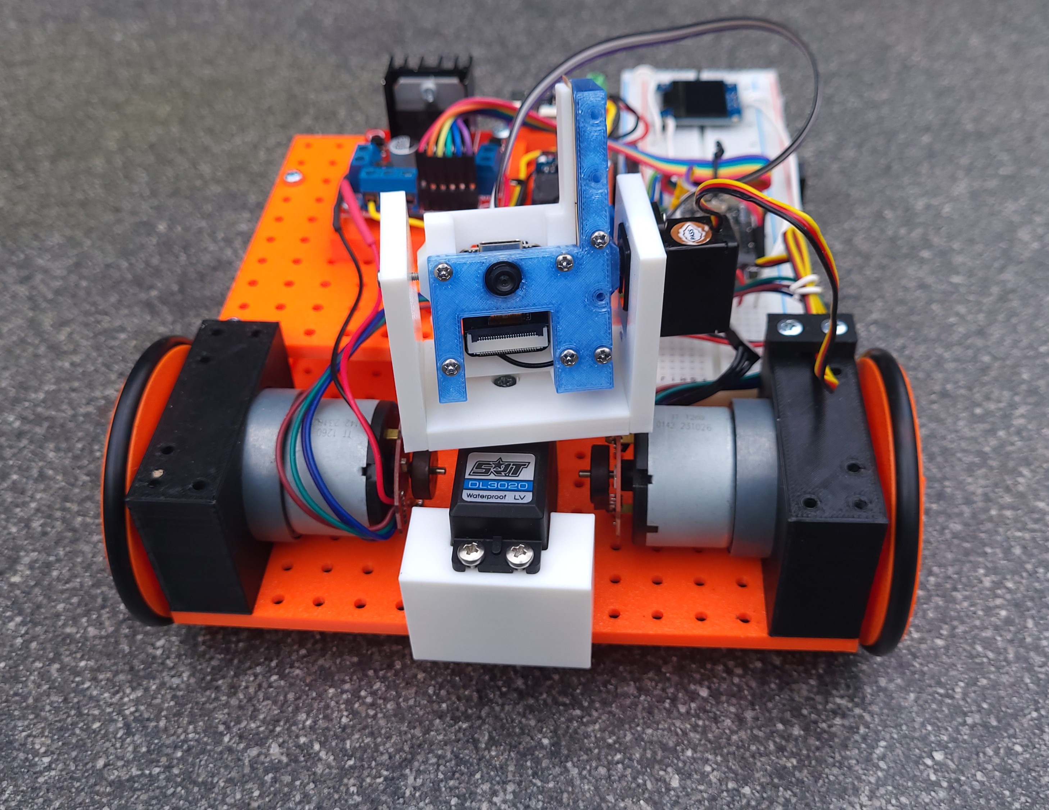
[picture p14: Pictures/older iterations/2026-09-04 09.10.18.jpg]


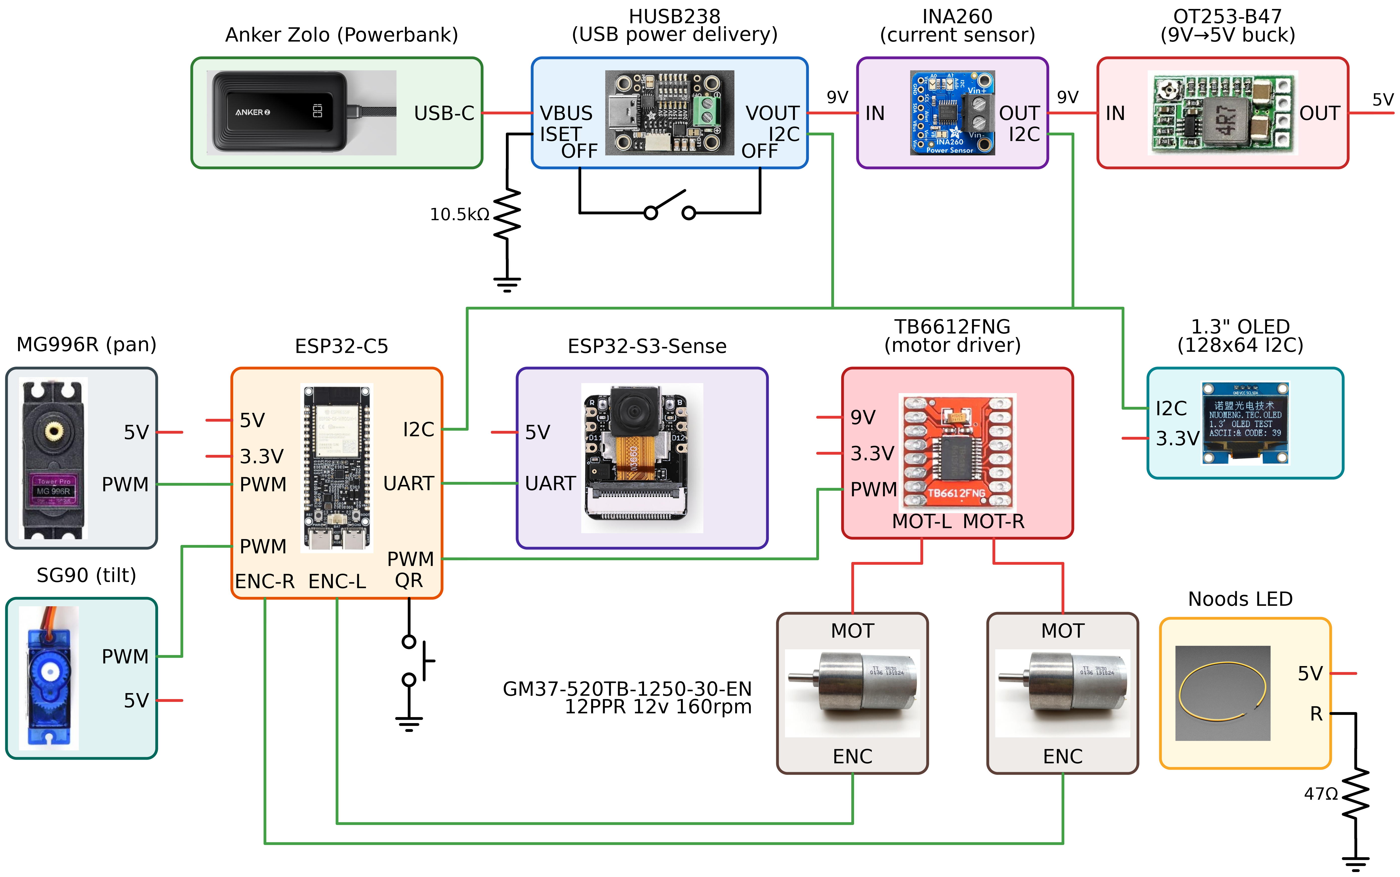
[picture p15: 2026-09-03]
Schematic/powerbank_circuit.png

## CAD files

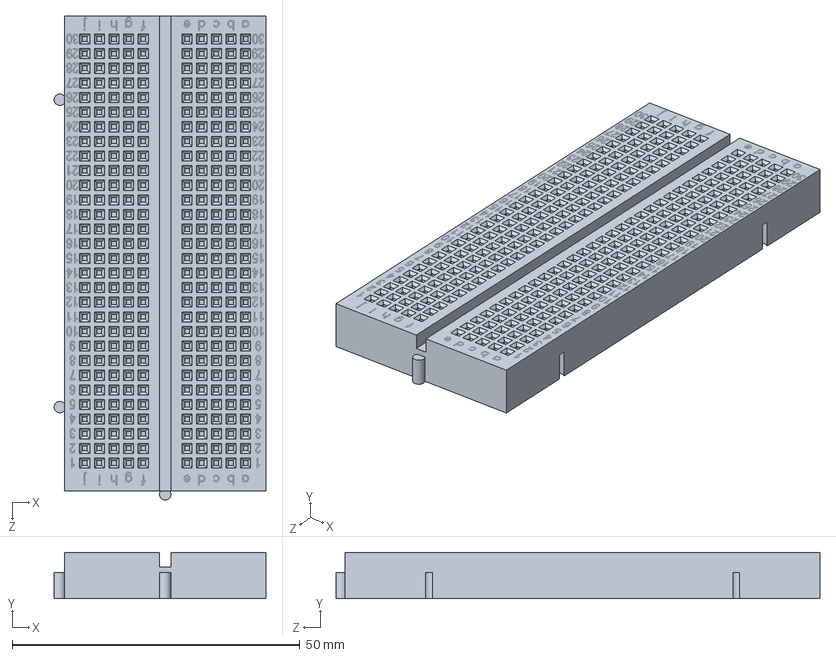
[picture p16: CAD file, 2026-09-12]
CAD/LynXP One Sept 2026/Solidworks/Main Half-Size Board.SLDPRT
36.8 x 8.00 x 84.1 mm

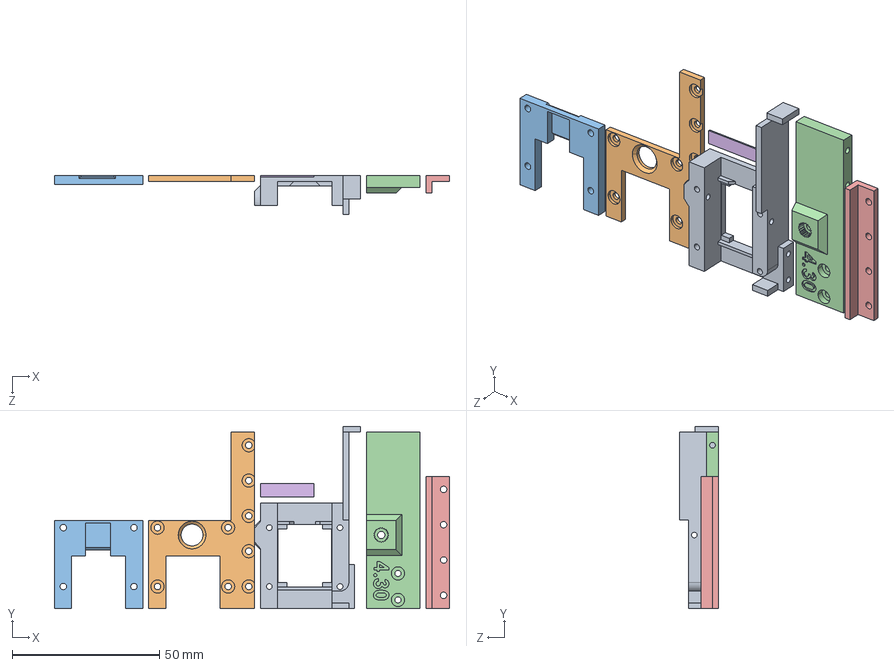
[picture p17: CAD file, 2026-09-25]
CAD/LynXP One Sept 2026/STEP/CamHolder.STEP
134.2 x 62.0 x 13.2 mm

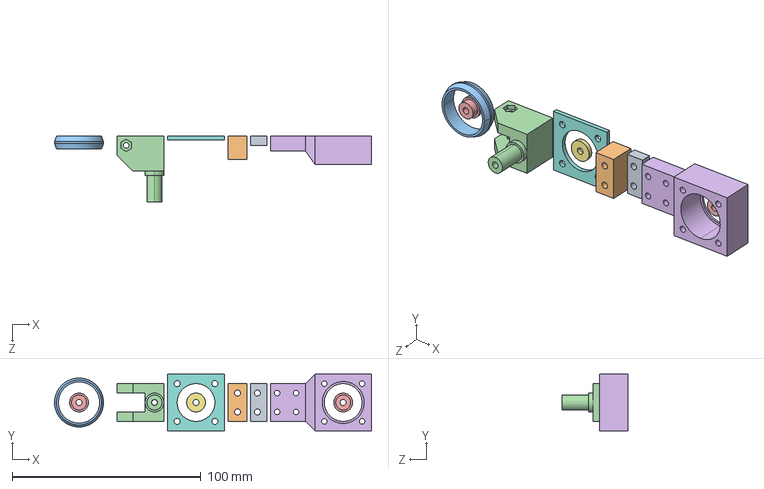
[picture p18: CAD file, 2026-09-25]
CAD/LynXP One Sept 2026/STEP/Caster.STEP
168.0 x 30.0 x 35.0 mm

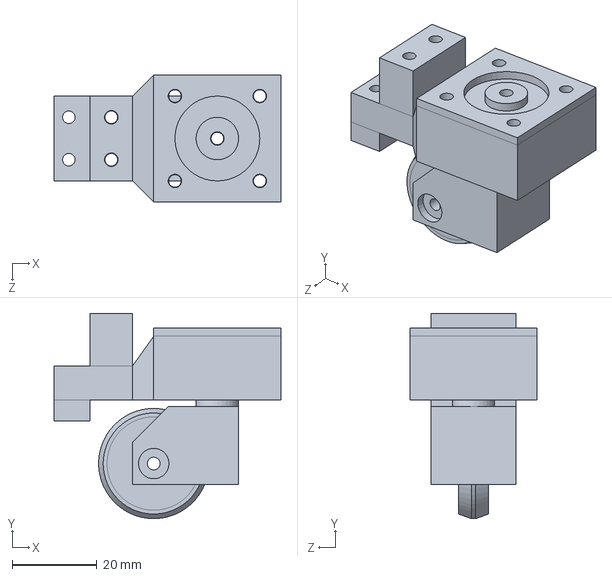
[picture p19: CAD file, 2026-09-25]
CAD/LynXP One Sept 2026/Solidworks/Caster3.SLDPRT
53.5 x 48.4 x 30.0 mm

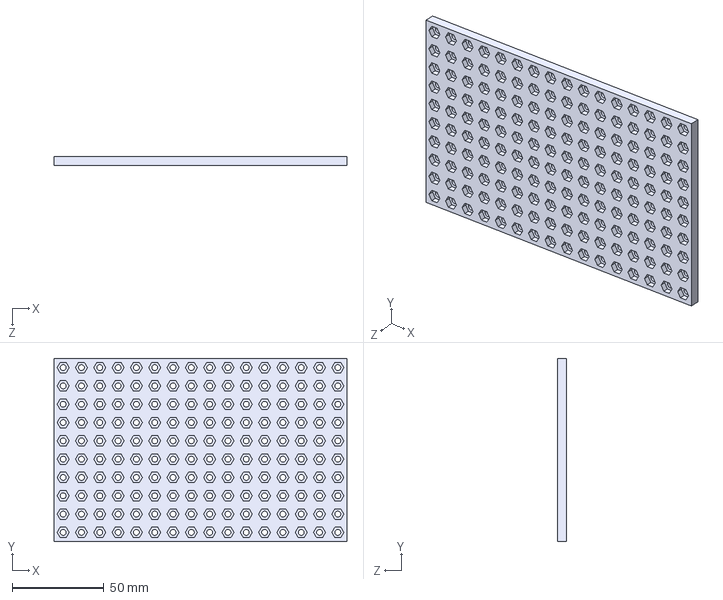
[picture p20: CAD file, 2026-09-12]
CAD/LynXP One Sept 2026/STEP/Frame_16x10.STEP
160.0 x 100.0 x 5.00 mm

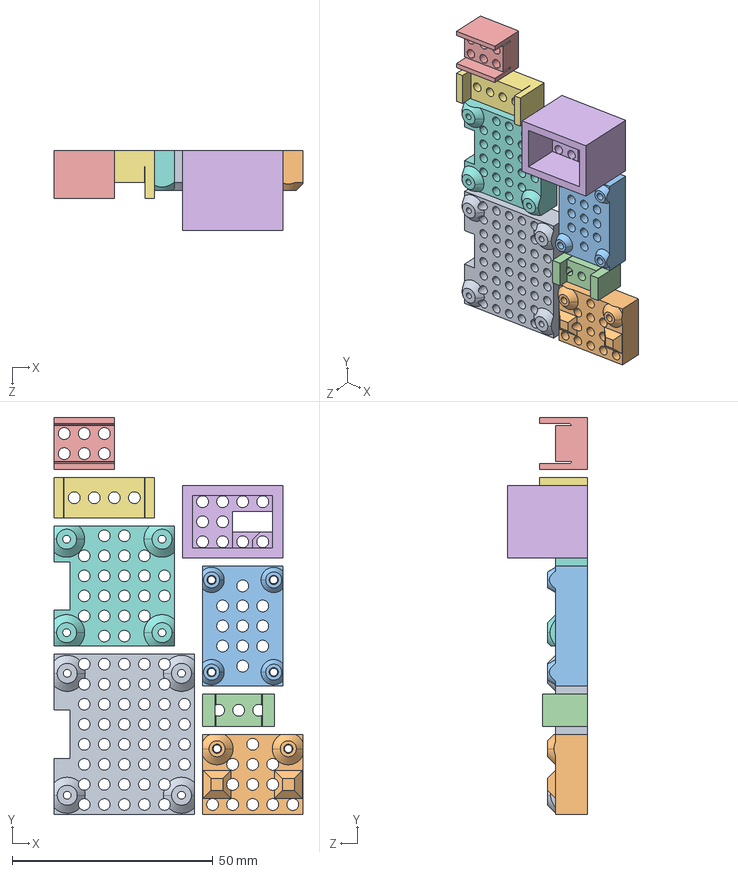
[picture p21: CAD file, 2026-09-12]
CAD/LynXP One Sept 2026/STEP/ElectronicsHolders.STEP
62.0 x 99.0 x 20.0 mm
Oled1.3_Holder
INA260Holder
HUSB238Holder
ButtonHolder
OT253Holder
PowerSwitchHolder
TB6612FNGHolder
Oled0.96_Holde

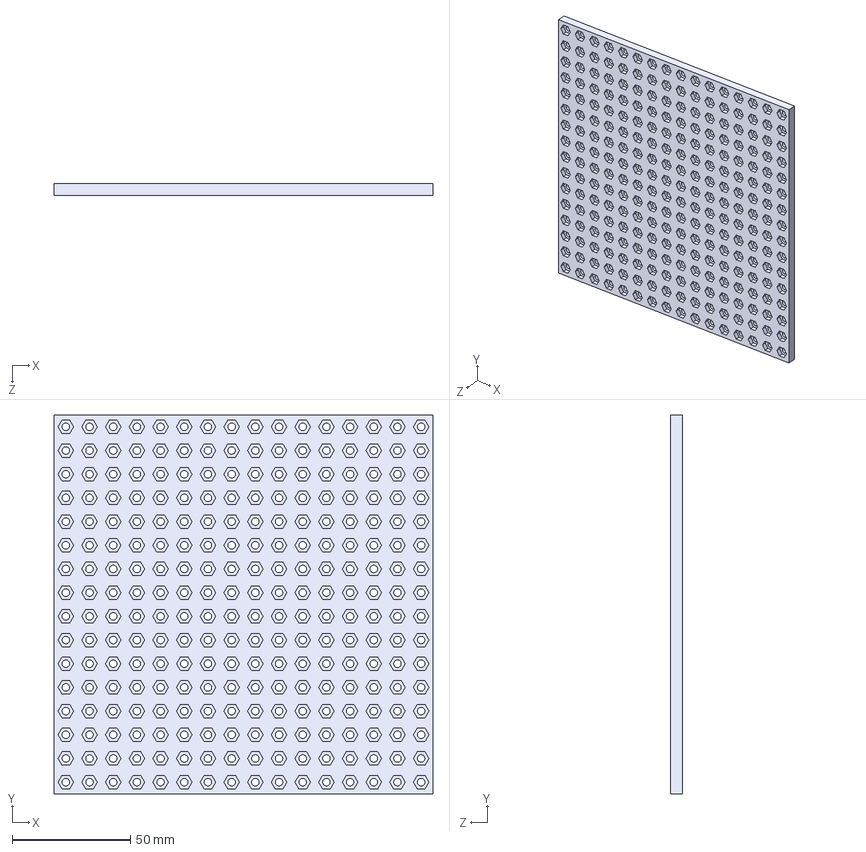
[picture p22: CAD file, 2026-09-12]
CAD/LynXP One Sept 2026/STEP/BottomFrame_16x16.STEP
160.0 x 160.0 x 5.00 mm

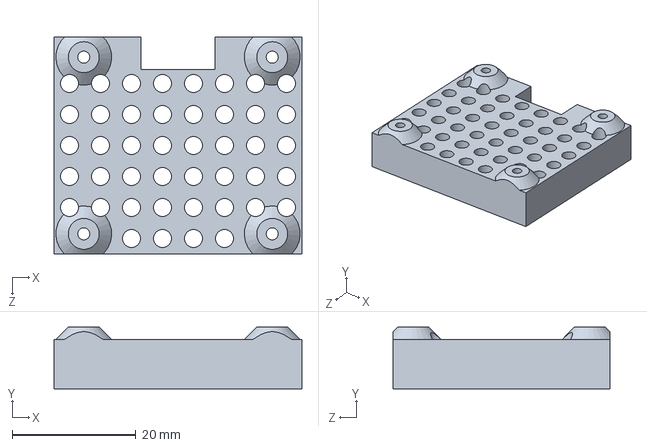
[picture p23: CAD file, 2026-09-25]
CAD/LynXP One Sept 2026/Solidworks/Oled1.3_Holder.SLDPRT
40.0 x 10.0 x 35.0 mm

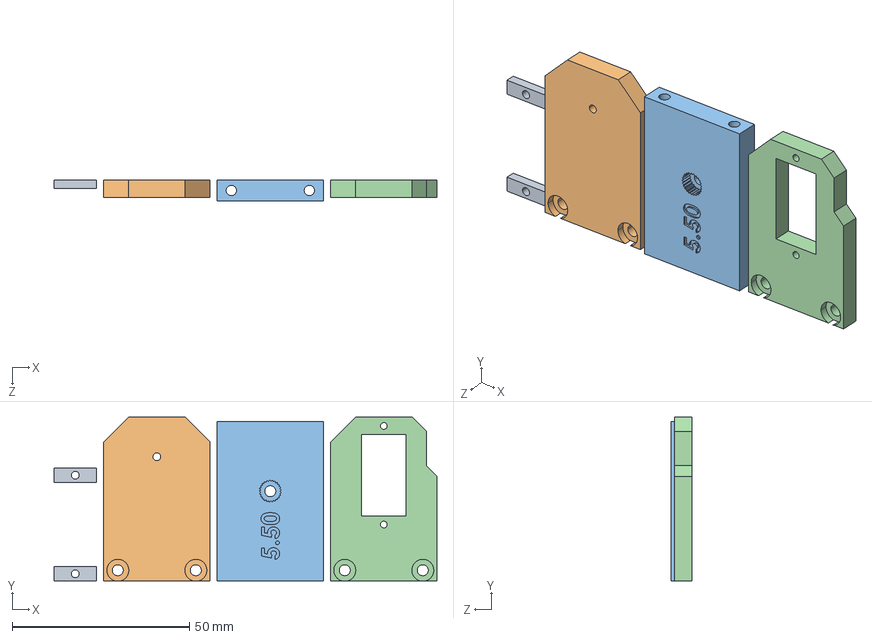
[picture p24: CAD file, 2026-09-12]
CAD/LynXP One Sept 2026/STEP/ServoBracket.STEP
108.0 x 46.2 x 6.00 mm

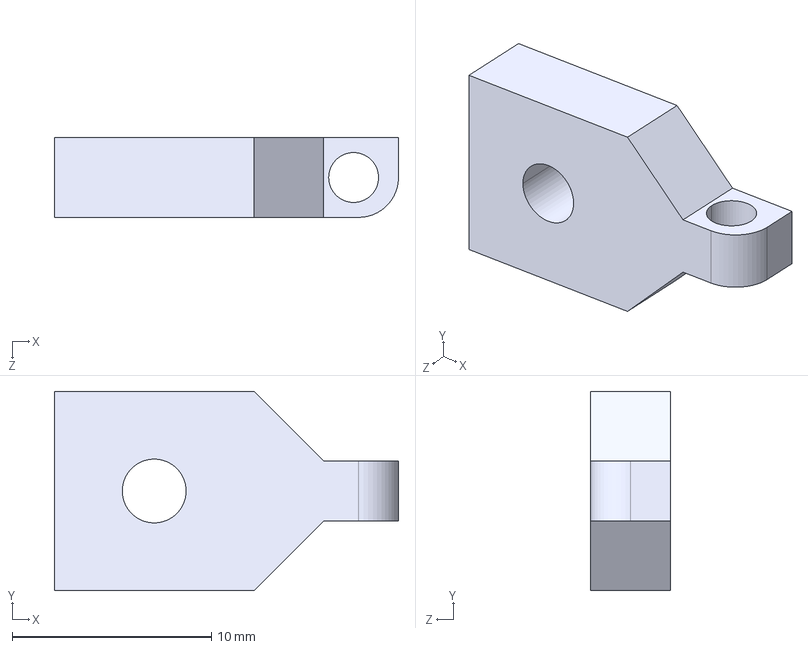
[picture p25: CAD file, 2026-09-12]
CAD/LynXP One Sept 2026/STEP/NoodsHolder.STEP
17.2 x 10.0 x 4.00 mm

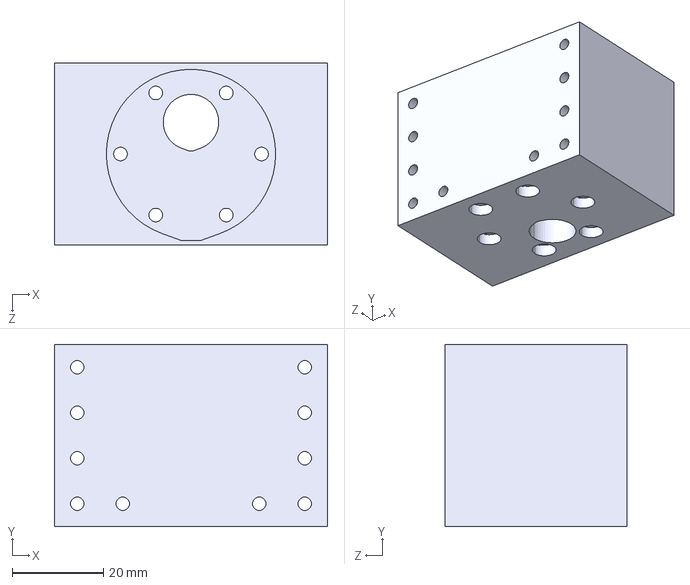
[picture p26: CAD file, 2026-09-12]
CAD/LynXP One Sept 2026/STEP/MotorMount 2x.STEP
60.0 x 40.0 x 40.0 mm

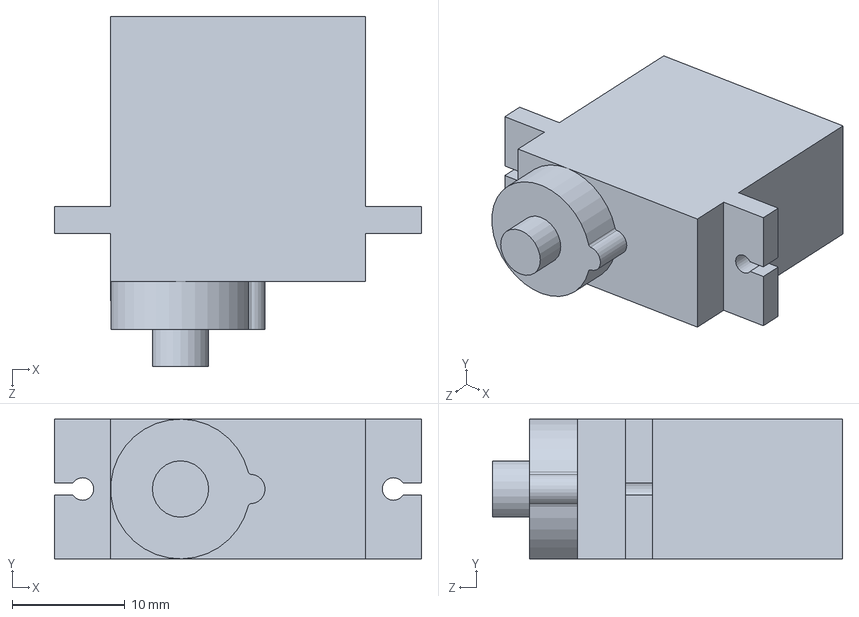
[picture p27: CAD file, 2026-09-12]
CAD/LynXP One Sept 2026/Solidworks/Servo Motor SG90.SLDPRT
32.6 x 12.4 x 31.1 mm

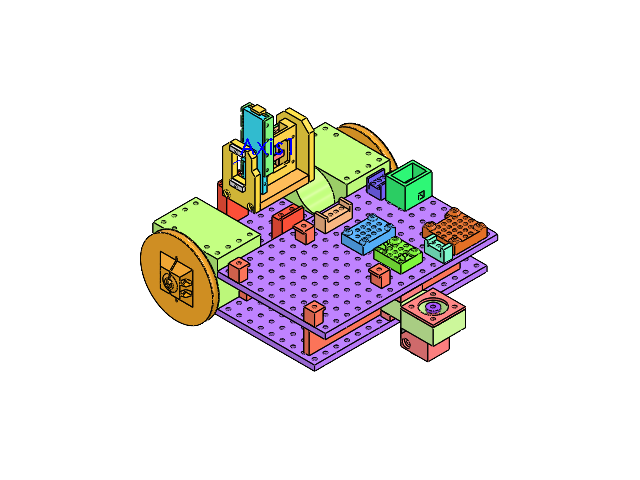
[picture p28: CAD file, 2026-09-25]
CAD/LynXP One Sept 2026/Solidworks/Frame_Assembly.SLDASM
BottomFrame
MotorMount x 2
Wheel_71.5mm x 2
Caster3
HUSB238Holder
Frame_16x10
StandardServoHolder
ServoBracket
CamHolder
Seeed Studio XIAO-ESP32-S3-Sense
BreadboardHolder_Clamp x 4
AnkerZoloHolder_Large
TB6612FNGHolder
INA260Holder
OT253Holder
PowerSwitchHolder
ButtonHolder
NoodsHolder x 2

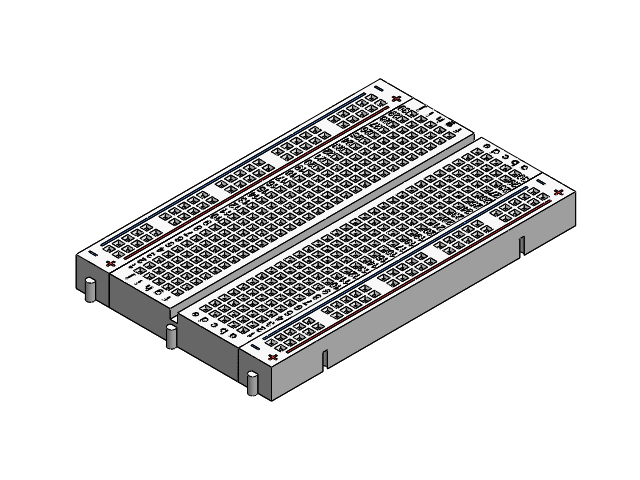
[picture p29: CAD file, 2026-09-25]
CAD/LynXP One Sept 2026/Solidworks/Half-Size Breadboard.SLDASM
Main Half-Size Board
Half-Size Side Rail x 2

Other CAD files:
CAD/LynXP One Sept 2026/Solidworks/LargeHorn_MultiDia.SLDASM
CAD/LynXP One Sept 2026/Solidworks/Cam_Assembly.SLDASM
CAD/LynXP One Sept 2026/Solidworks/CamHorn_MultiDia.SLDASM
CAD/LynXP One Sept 2026/Solidworks/CompleteAssembly.SLDASM
CAD/LynXP One Sept 2026/STEP/AnkerZoloHolder_Large.STEP
CAD/LynXP One Sept 2026/STEP/BreadboardHolder_Clamp.STEP
CAD/LynXP One Sept 2026/STEP/Servo horns and tests.STEP
CAD/LynXP One Sept 2026/STEP/StandardServoHolder.STEP
CAD/LynXP One Sept 2026/STEP/Wheel_71.5mm.STEP
CAD/LynXP One Sept 2026/Solidworks/AnkerZoloHolder_Large.SLDPRT
CAD/LynXP One Sept 2026/Solidworks/AnkerZoloPowerbank.SLDPRT
CAD/LynXP One Sept 2026/Solidworks/BottomFrame.SLDPRT
CAD/LynXP One Sept 2026/Solidworks/BreadboardHolder_Clamp.SLDPRT
CAD/LynXP One Sept 2026/Solidworks/ButtonHolder.SLDPRT
CAD/LynXP One Sept 2026/Solidworks/CamHolder.SLDPRT
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

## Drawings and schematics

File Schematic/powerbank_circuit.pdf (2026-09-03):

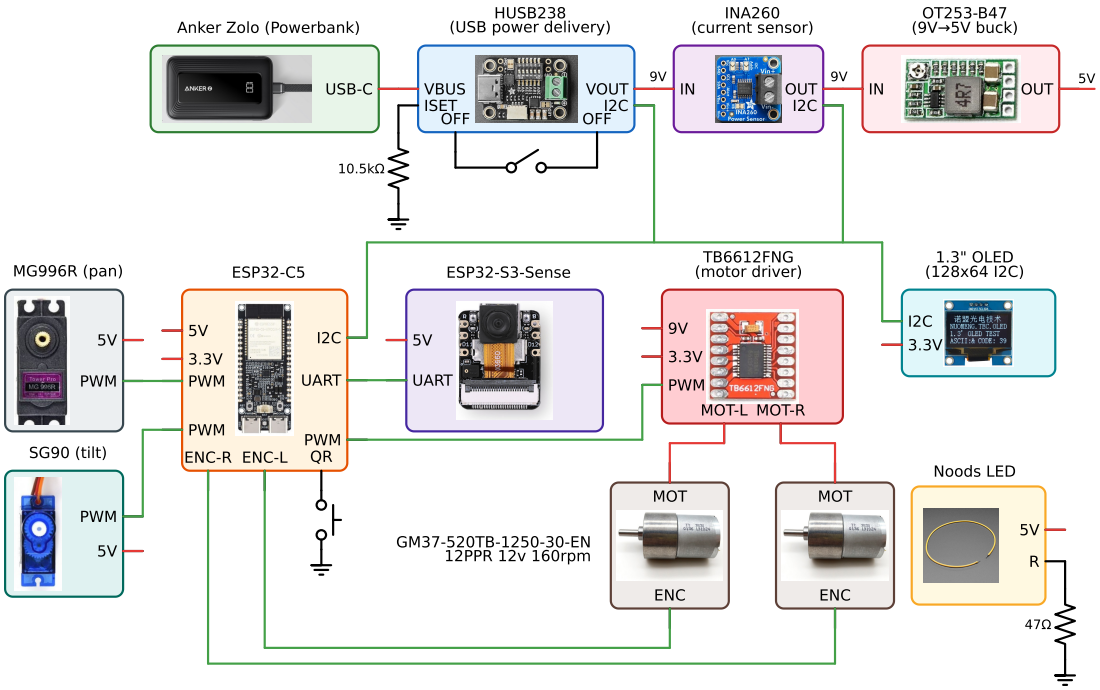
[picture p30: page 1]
USB-C; VBUS ISET; VOUT I2C; OFF; OUT; INA260 (current sensor); OT253-B47 (9V→5V buck); PWM; MG996R (pan); SG90 (tilt); 3.3V PWM; UART; ENC-R ENC-L; ESP32-C5; ESP32-S3-Sense; PWM MOT-L MOT-R; TB6612FNG (motor driver); MOT; ENC; GM37-520TB-1250-30-EN 12PPR 12v 160rpm; 1.3" OLED (128x64 I2C); Noods LED

HUSB238
(USB power delivery)

Anker Zolo (Powerbank)

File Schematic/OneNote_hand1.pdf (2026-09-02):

# Power schematic

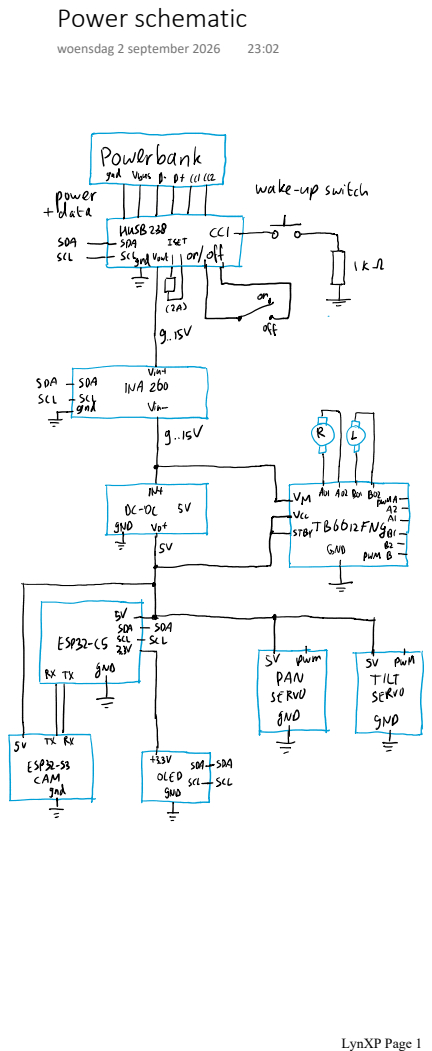
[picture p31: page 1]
woensdag 2 september 2026; LynXP Page 1

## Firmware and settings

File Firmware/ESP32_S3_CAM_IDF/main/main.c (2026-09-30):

// XIAO ESP32S3 Sense: low-latency MJPEG stream over WiFi for remote robot control.
#include <string.h>
#include <stdlib.h>
#include <sys/socket.h>
#include <sys/time.h>
#include <netinet/in.h>
#include <netinet/tcp.h>

#include "freertos/FreeRTOS.h"
#include "freertos/task.h"
#include "freertos/event_groups.h"
#include "freertos/semphr.h"
#include "esp_wifi.h"
#include "esp_event.h"
#include "esp_log.h"
#include "esp_mac.h"
#include "esp_netif.h"
#include "esp_http_server.h"
#include "esp_heap_caps.h"
#include "esp_system.h"
#include "esp_timer.h"
#include "esp_attr.h"
#include "nvs_flash.h"
#include "esp_camera.h"
#include "driver/uart.h"
#include "nvs.h"
#include "esp_ota_ops.h"
#include "esp_app_desc.h"

static const char *TAG = "cam";

// XIAO ESP32S3 Sense camera pin map (OV3660). Confirmed against Espressif's
// arduino-esp32 camera_pins.h, CAMERA_MODEL_XIAO_ESP32S3 block.
#define PWDN_GPIO_NUM  -1
#define RESET_GPIO_NUM -1
#define XCLK_GPIO_NUM  10
#define SIOD_GPIO_NUM  40
#define SIOC_GPIO_NUM  39
#define Y9_GPIO_NUM    48
#define Y8_GPIO_NUM    11
#define Y7_GPIO_NUM    12
#define Y6_GPIO_NUM    14
#define Y5_GPIO_NUM    16
#define Y4_GPIO_NUM    18
#define Y3_GPIO_NUM    17
#define Y2_GPIO_NUM    15
#define VSYNC_GPIO_NUM 38
#define HREF_GPIO_NUM  47
#define PCLK_GPIO_NUM  13

static char s_mac_str[18];
static char s_ip_str[16] = "0.0.0.0";

// Diagnostics for the STAT UART line below -- see its own comment for what
// each one is trying to distinguish (WiFi vs. power/brownout vs. camera-bus
// noise as the cause of a stuttering/dead stream).
//
// RTC_DATA_ATTR: survives a brownout/watchdog/panic/software reset (exactly
// the reboots this is trying to count), but re-zeroes on a true power cycle
// (VDD fully off then back on) -- "reboots since this was last plugged in"
// is the useful number here, not a lifetime total that would need NVS wear
// to persist.
RTC_DATA_ATTR static uint32_t s_reboot_count = 0;
// Count of esp_camera_fb_get() returning NULL -- unlike a WiFi drop or a
// full reset, a camera/DVP-bus glitch (e.g. from nearby motor EMI) can stall
// frame capture without disturbing the network link or crashing the chip at
// all, so this is the one field that can catch that case specifically.
// Deliberately NOT RTC-persisted: it's a per-boot count, and a fresh boot
// having zero stutters so far is exactly right.
static volatile uint32_t s_cam_fail_count = 0;

// Frame-interval and network-send timing -- unlike camfail (a hard
// esp_camera_fb_get() NULL), these catch a frame that succeeds but arrives
// LATE, either because the capture side stalled (camera/DVP bus contention)
// or because pushing the previous frame out over the socket took unusually
// long (network-side delay actually affecting the live stream, not a
// synthetic ping -- see diag.html's whole reason for existing). "Slow"
// thresholds are generous (a normal frame at even 10 fps is 100ms apart) so
// only genuine multi-frame-period stalls count, not routine jitter.
#define FRAME_INTERVAL_SLOW_MS 200
#define SEND_SLOW_MS 200

static volatile uint32_t s_frame_count = 0;
static volatile uint32_t s_last_frame_interval_ms = 0;
static volatile uint32_t s_max_frame_interval_ms = 0;
static volatile uint32_t s_slow_frame_count = 0;

// Written by whichever stream_client_task most recently pushed a frame --
// with normally at most one viewer this is that viewer's timing; with
// several, it's just whichever sent last, good enough for "is the network
// currently struggling" without the bookkeeping of per-client stats.
static volatile uint32_t s_last_send_ms = 0;
static volatile uint32_t s_max_send_ms = 0;
static volatile uint32_t s_slow_send_count = 0;

static void status_uart_send(void);
static int get_active_clients(void);
static void hex_encode(const char *in, char *out, size_t out_len);

// Full esp_reset_reason_t as of IDF v6.1 -- notably including USB/JTAG,
// which are the common, benign cases on this board during development (its
// native USB peripheral is both the flashing interface and the RTS-toggle
// reset line a serial monitor uses), so they shouldn't get lumped into a
// generic "UNKNOWN" that would otherwise look like a real problem.
static const char *reset_reason_str(esp_reset_reason_t reason) {
    switch (reason) {
        case ESP_RST_UNKNOWN:    return "UNKNOWN";
        case ESP_RST_POWERON:    return "POWERON";
        case ESP_RST_EXT:        return "EXT";
        case ESP_RST_SW:         return "SW";
        case ESP_RST_PANIC:      return "PANIC";
        case ESP_RST_INT_WDT:    return "INT_WDT";
        case ESP_RST_TASK_WDT:   return "TASK_WDT";
        case ESP_RST_WDT:        return "WDT";
        case ESP_RST_DEEPSLEEP:  return "DEEPSLEEP";
        case ESP_RST_BROWNOUT:   return "BROWNOUT";
        case ESP_RST_SDIO:       return "SDIO";
        case ESP_RST_USB:        return "USB";
        case ESP_RST_JTAG:       return "JTAG";
        case ESP_RST_EFUSE:      return "EFUSE";
        case ESP_RST_PWR_GLITCH: return "PWR_GLITCH";
        case ESP_RST_CPU_LOCKUP: return "CPU_LOCKUP";
        default:                 return "UNRECOGNIZED";
    }
}

// ---------------------------------------------------------------------------
// WiFi. No compiled-in credentials: the robot (ESP32-C5) owns the list of
// networks and its setup UI, and tells this camera which network to join
// over the status UART ("WIFI ssid=<hex> pass=<hex>", see
// status_uart_rx_task()) whenever the camera isn't on the same network as
// the robot. The camera remembers every network it's been given (most
// recent first, in NVS), so after a reboot it rejoins by itself without
// waiting for the robot -- and still works standalone on USB for testing.
//
// This S3 is 2.4 GHz only; the robot knows that and won't send a 5 GHz-only
// network (its own C5 radio does both bands).
// ---------------------------------------------------------------------------

#define CAM_WIFI_MAX 10
#define WIFI_CONNECT_TIMEOUT_MS 15000
#define WIFI_RETRY_INTERVAL_MS 3000

typedef struct {
    char ssid[33];
    char pass[65];
} cam_wifi_net_t;

#define WIFI_CONNECTED_BIT BIT0
#define WIFI_FAILED_BIT    BIT1
#define WIFI_PUSH_BIT      BIT2  // the robot sent a network to switch to
#define WIFI_SCAN_BIT      BIT3  // the robot asked what networks this camera can hear
#define SCAN_PASSIVE_MS    150   // listen-only channels need to catch at least one ~102 ms beacon
#define SCAN_REPORT_MAX    30

static void status_uart_write(const char *line, int len);
static void ota_mark_valid_once(void);

static EventGroupHandle_t s_wifi_event_group;
static SemaphoreHandle_t s_wifi_lock;
static cam_wifi_net_t s_nets[CAM_WIFI_MAX]; // most recently used/pushed first
static int s_net_count = 0;
static volatile bool s_wifi_connected = false;
static char s_attempt_ssid[33] = "";
static char s_connected_ssid[33] = "";
static char s_pending_ssid[33] = "";       // set by a push; wifi_task switches to it

static void copy_str(char *dst, size_t dst_len, const char *src) {
    size_t n = strnlen(src, dst_len - 1);
    memcpy(dst, src, n);
    dst[n] = '\0';
}

// wifi_config_t's ssid[32]/password[64] aren't NUL-terminated when full.
static void copy_field(uint8_t *dst, size_t dst_len, const char *src) {
    memset(dst, 0, dst_len);
    size_t n = strlen(src);
    memcpy(dst, src, n < dst_len ? n : dst_len);
}

static void nets_save_locked(void) {
    nvs_handle_t h;
    if (nvs_open("camwifi", NVS_READWRITE, &h) != ESP_OK) return;
    if (s_net_count > 0) {
        nvs_set_blob(h, "nets", s_nets, s_net_count * sizeof(cam_wifi_net_t));
    } else {
        nvs_erase_key(h, "nets");
    }
    nvs_commit(h);
    nvs_close(h);
}

// Moves (or inserts) a network to the front of the list. Only writes flash
// if something actually changed. Returns true if the list changed.
static bool nets_promote_locked(const char *ssid, const char *pass) {
    if (s_net_count > 0 && strcmp(s_nets[0].ssid, ssid) == 0 && strcmp(s_nets[0].pass, pass) == 0) return false;
    cam_wifi_net_t entry = {0};
    copy_str(entry.ssid, sizeof(entry.ssid), ssid);
    copy_str(entry.pass, sizeof(entry.pass), pass);
    int existing = -1;
    for (int i = 0; i < s_net_count; i++) {
        if (strcmp(s_nets[i].ssid, ssid) == 0) { existing = i; break; }
    }
    int shift_end = existing >= 0 ? existing : (s_net_count < CAM_WIFI_MAX ? s_net_count++ : CAM_WIFI_MAX - 1);
    memmove(&s_nets[1], &s_nets[0], shift_end * sizeof(cam_wifi_net_t));
    s_nets[0] = entry;
    nets_save_locked();
    return true;
}

// Loads the remembered list. On the very first boot of this firmware the
// list doesn't exist yet: seed it with whatever network the WiFi driver last
// used (it persists that itself) -- i.e. the one the old hardcoded-credentials
// firmware was on -- so updating doesn't knock the camera offline.
static void nets_load(void) {
    nvs_handle_t h;
    size_t len = sizeof(s_nets);
    bool found = false;
    if (nvs_open("camwifi", NVS_READONLY, &h) == ESP_OK) {
        found = nvs_get_blob(h, "nets", s_nets, &len) == ESP_OK;
        uint8_t migrated = 0;
        if (nvs_get_u8(h, "migrated", &migrated) == ESP_OK && migrated) found = true;
        nvs_close(h);
    }
    s_net_count = found ? (int) (len / sizeof(cam_wifi_net_t)) : 0;
    for (int i = 0; i < s_net_count; i++) {
        s_nets[i].ssid[32] = '\0';
        s_nets[i].pass[64] = '\0';
    }

    if (!found) {
        wifi_config_t cfg = {0};
        if (esp_wifi_get_config(WIFI_IF_STA, &cfg) == ESP_OK && cfg.sta.ssid[0] != '\0') {
            char ssid[33] = {0}, pass[65] = {0};
            memcpy(ssid, cfg.sta.ssid, sizeof(cfg.sta.ssid));
            memcpy(pass, cfg.sta.password, sizeof(cfg.sta.password));
            nets_promote_locked(ssid, pass);
            ESP_LOGI(TAG, "Imported last-used network \"%s\"", ssid);
        }
        if (nvs_open("camwifi", NVS_READWRITE, &h) == ESP_OK) {
            nvs_set_u8(h, "migrated", 1);
            nvs_commit(h);
            nvs_close(h);
        }
    }
    ESP_LOGI(TAG, "%d remembered network(s)", s_net_count);
}

// Called from the UART RX task when the robot sends a network.
static void wifi_handle_push(const char *ssid, const char *pass) {
    if (ssid[0] == '\0') return;
    xSemaphoreTake(s_wifi_lock, portMAX_DELAY);
    bool changed = nets_promote_locked(ssid, pass);
    bool switch_needed = !s_wifi_connected || strcmp(s_connected_ssid, ssid) != 0;
    if (switch_needed) copy_str(s_pending_ssid, sizeof(s_pending_ssid), ssid);
    xSemaphoreGive(s_wifi_lock);
    if (switch_needed) {
        ESP_LOGI(TAG, "Robot says: join \"%s\"%s", ssid, changed ? " (new/updated)" : "");
        xEventGroupSetBits(s_wifi_event_group, WIFI_PUSH_BIT);
    }
}

static void wifi_event_handler(void *arg, esp_event_base_t event_base,
                                int32_t event_id, void *event_data) {
    if (event_base == WIFI_EVENT && event_id == WIFI_EVENT_STA_DISCONNECTED) {
        wifi_event_sta_disconnected_t *event = (wifi_event_sta_disconnected_t *)event_data;
        ESP_LOGW(TAG, "WiFi %s, reason=%d", s_wifi_connected ? "disconnected" : "connect failed", event->reason);
        s_wifi_connected = false;
        snprintf(s_ip_str, sizeof(s_ip_str), "0.0.0.0");
        xEventGroupSetBits(s_wifi_event_group, WIFI_FAILED_BIT);
    } else if (event_base == IP_EVENT && event_id == IP_EVENT_STA_GOT_IP) {
        ip_event_got_ip_t *event = (ip_event_got_ip_t *)event_data;
        snprintf(s_ip_str, sizeof(s_ip_str), IPSTR, IP2STR(&event->ip_info.ip));
        copy_str(s_connected_ssid, sizeof(s_connected_ssid), s_attempt_ssid);
        s_wifi_connected = true;
        ESP_LOGI(TAG, "Connected to %s - stream ready at http://%s/ (MJPEG on port 81)", s_connected_ssid, s_ip_str);
        status_uart_send(); // push the new IP to the C5 immediately instead of waiting for the next heartbeat
        ota_mark_valid_once(); // a freshly OTA'd image has now proven itself
        xEventGroupSetBits(s_wifi_event_group, WIFI_CONNECTED_BIT);
    }
}

static bool wifi_attempt(const char *ssid) {
    cam_wifi_net_t net = {0};
    bool known = false;
    xSemaphoreTake(s_wifi_lock, portMAX_DELAY);
    for (int i = 0; i < s_net_count; i++) {
        if (strcmp(s_nets[i].ssid, ssid) == 0) { net = s_nets[i]; known = true; break; }
    }
    if (known) copy_str(s_attempt_ssid, sizeof(s_attempt_ssid), ssid);
    xSemaphoreGive(s_wifi_lock);
    if (!known) return false;

    ESP_LOGI(TAG, "Connecting to WiFi: %s", net.ssid);
    wifi_config_t wifi_cfg = {0};
    copy_field(wifi_cfg.sta.ssid, sizeof(wifi_cfg.sta.ssid), net.ssid);
    copy_field(wifi_cfg.sta.password, sizeof(wifi_cfg.sta.password), net.pass);
    wifi_cfg.sta.threshold.authmode = net.pass[0] ? WIFI_AUTH_WPA2_PSK : WIFI_AUTH_OPEN;

    xEventGroupClearBits(s_wifi_event_group, WIFI_CONNECTED_BIT | WIFI_FAILED_BIT);
    if (esp_wifi_set_config(WIFI_IF_STA, &wifi_cfg) != ESP_OK || esp_wifi_connect() != ESP_OK) return false;
    EventBits_t bits = xEventGroupWaitBits(s_wifi_event_group, WIFI_CONNECTED_BIT | WIFI_FAILED_BIT,
                                           pdFALSE, pdFALSE, pdMS_TO_TICKS(WIFI_CONNECT_TIMEOUT_MS));
    if ((bits & WIFI_CONNECTED_BIT) && s_wifi_connected) return true;
    esp_wifi_disconnect();
    return false;
}

// Scans, then tries the most recently used remembered network that's in
// range. A network pushed by the robot is tried straight away (no scan
// needed, so hidden networks work too). Retries forever, and rejoins after
// any later disconnect.
static const wifi_scan_config_t SCAN_CFG = {
    .show_hidden = false,
    .scan_type = WIFI_SCAN_TYPE_ACTIVE,
    .scan_time.active.min = 60,
    .scan_time.active.max = 120,
    .scan_time.passive = SCAN_PASSIVE_MS,
    .home_chan_dwell_time = WIFI_SCAN_HOME_CHANNEL_DWELL_DEFAULT_TIME,
};

// Scans and reports every network heard to the robot, one
// "AP ssid=<hex> rssi=<dBm> ch=<n> sec=<0|1>" line each (strongest access
// point per SSID), then "APEND". This camera's external antenna often hears
// 2.4 GHz networks the robot's own board antenna misses. While streaming,
// this briefly stalls the picture -- it only runs when asked.
static void scan_and_report(void) {
    uint16_t n = SCAN_REPORT_MAX;
    wifi_ap_record_t *records = malloc(n * sizeof(wifi_ap_record_t));
    int sent = 0;
    if (records && esp_wifi_scan_start(&SCAN_CFG, true) == ESP_OK &&
        esp_wifi_scan_get_ap_records(&n, records) == ESP_OK) {
        for (int i = 0; i < n; i++) {
            const char *ssid = (const char *)records[i].ssid;
            if (ssid[0] == '\0') continue;
            bool dup = false; // records come strongest first, so the first of each SSID wins
            for (int j = 0; j < i && !dup; j++) dup = strcmp((const char *)records[j].ssid, ssid) == 0;
            if (dup) continue;
            char hex[67];
            hex_encode(ssid, hex, sizeof(hex));
            char line[128];
            int len = snprintf(line, sizeof(line), "AP ssid=%s rssi=%d ch=%d sec=%d\n", hex, records[i].rssi,
                               records[i].primary, records[i].authmode != WIFI_AUTH_OPEN);
            status_uart_write(line, len);
            sent++;
        }
    }
    free(records);
    esp_wifi_clear_ap_list();
    status_uart_write("APEND\n", 6);
    ESP_LOGI(TAG, "Reported %d network(s) to the robot", sent);
}

static void wifi_task(void *arg) {
    while (true) {
        if (!s_wifi_connected) {
            char target[33] = "";
            xSemaphoreTake(s_wifi_lock, portMAX_DELAY);
            copy_str(target, sizeof(target), s_pending_ssid);
            s_pending_ssid[0] = '\0';
            int count = s_net_count;
            xSemaphoreGive(s_wifi_lock);

            if (target[0] == '\0' && count > 0 && esp_wifi_scan_start(&SCAN_CFG, true) == ESP_OK) {
                uint16_t n = 20;
                wifi_ap_record_t *records = malloc(n * sizeof(wifi_ap_record_t));
                if (records && esp_wifi_scan_get_ap_records(&n, records) == ESP_OK) {
                    xSemaphoreTake(s_wifi_lock, portMAX_DELAY);
                    for (int i = 0; i < s_net_count && target[0] == '\0'; i++) {
                        for (int j = 0; j < n; j++) {
                            if (strcmp((const char *)records[j].ssid, s_nets[i].ssid) == 0) {
                                copy_str(target, sizeof(target), s_nets[i].ssid);
                                break;
                            }
                        }
                    }
                    xSemaphoreGive(s_wifi_lock);
                }
                free(records);
                esp_wifi_clear_ap_list();
            }

            if (target[0] != '\0' && wifi_attempt(target)) continue;
            // Wait out the retry interval -- or less, if the robot sends a network.
            EventBits_t woke = xEventGroupWaitBits(s_wifi_event_group, WIFI_PUSH_BIT | WIFI_SCAN_BIT, pdTRUE, pdFALSE,
                                                   pdMS_TO_TICKS(WIFI_RETRY_INTERVAL_MS));
            if (woke & WIFI_SCAN_BIT) scan_and_report();
            continue;
        }

        EventBits_t bits = xEventGroupWaitBits(s_wifi_event_group, WIFI_FAILED_BIT | WIFI_PUSH_BIT | WIFI_SCAN_BIT,
                                               pdTRUE, pdFALSE, portMAX_DELAY);
        if (bits & WIFI_SCAN_BIT) scan_and_report();
        if ((bits & WIFI_PUSH_BIT) && s_wifi_connected) {
            // The robot is on a different network -- follow it.
            esp_wifi_disconnect();
            xEventGroupWaitBits(s_wifi_event_group, WIFI_FAILED_BIT, pdTRUE, pdFALSE, pdMS_TO_TICKS(3000));
            s_wifi_connected = false;
        }
    }
}

static void wifi_start(void) {
    s_wifi_lock = xSemaphoreCreateMutex();
    esp_netif_create_default_wifi_sta();

    wifi_init_config_t init_cfg = WIFI_INIT_CONFIG_DEFAULT();
    ESP_ERROR_CHECK(esp_wifi_init(&init_cfg));

    esp_event_handler_instance_t wifi_handler, ip_handler;
    ESP_ERROR_CHECK(esp_event_handler_instance_register(
        WIFI_EVENT, ESP_EVENT_ANY_ID, &wifi_event_handler, NULL, &wifi_handler));
    ESP_ERROR_CHECK(esp_event_handler_instance_register(
        IP_EVENT, IP_EVENT_STA_GOT_IP, &wifi_event_handler, NULL, &ip_handler));

    nets_load(); // after esp_wifi_init(): the first-boot import reads the driver's persisted config

    ESP_ERROR_CHECK(esp_wifi_set_mode(WIFI_MODE_STA));
    ESP_ERROR_CHECK(esp_wifi_start());
    ESP_ERROR_CHECK(esp_wifi_set_ps(WIFI_PS_NONE)); // no modem sleep - lowest latency

    xTaskCreate(wifi_task, "wifi", 4096, NULL, tskIDLE_PRIORITY + 2, NULL);
}

// ---------------------------------------------------------------------------
// Camera
// ---------------------------------------------------------------------------
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
void app_main(void) {
    s_reboot_count++;
    ESP_LOGI(TAG, "Boot #%lu, reset reason: %s", (unsigned long) s_reboot_count,
             reset_reason_str(esp_reset_reason()));

    ESP_ERROR_CHECK(nvs_flash_init());
    s_ota_mutex = xSemaphoreCreateMutex();
    ota_creds_load();
    ESP_ERROR_CHECK(esp_netif_init());
    ESP_ERROR_CHECK(esp_event_loop_create_default());
    s_wifi_event_group = xEventGroupCreate();

    // Read straight from efuse - works even before the WiFi driver starts,
    // so this is available immediately at boot regardless of whether a
    // configured network is ever in range.
    uint8_t mac[6];
    esp_read_mac(mac, ESP_MAC_WIFI_STA);
    snprintf(s_mac_str, sizeof(s_mac_str), "%02X:%02X:%02X:%02X:%02X:%02X",
             mac[0], mac[1], mac[2], mac[3], mac[4], mac[5]);
    ESP_LOGI(TAG, "MAC address: %s", s_mac_str);

    status_uart_init();
    xTaskCreate(status_uart_task, "status_uart", 3072, NULL, tskIDLE_PRIORITY + 1, NULL);

    if (!init_camera()) {
        ESP_LOGE(TAG, "Halting: camera init failed");
        while (true) vTaskDelay(pdMS_TO_TICKS(1000));
    }

    // Non-blocking: joins (and keeps rejoining) in the background. The HTTP
    // servers don't need an IP to start -- they just become reachable once
    // one arrives.
    wifi_start();
    xTaskCreate(status_uart_rx_task, "status_uart_rx", 3072, NULL, tskIDLE_PRIORITY + 1, NULL);

    start_camera_server();
}

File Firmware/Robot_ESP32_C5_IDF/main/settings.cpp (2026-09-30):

#include "settings.hpp"

#include "nvs.h"
#include "esp_log.h"

#include <cmath>
#include <cstring>

// Ported from Robot_Pico2W_SDK/src/settings.cpp. applyDefaultSettings() is
// unchanged field-for-field. saveSettings()/loadSettings() are rewritten on
// NVS (namespace "robot", key "settings") instead of a raw byte-dump to
// littlefs's /settings.dat -- no flash_safe_execute()/multicore_lockout
// equivalent is needed here, NVS handles its own cache-disable window
// internally without needing the caller to pause anything.

namespace {

// Bumped from the Pico firmware's 16: struct padding and int/bool layout
// differ between arm-none-eabi and xtensa-esp32s3-elf, so the first ESP32
// boot must fall through to applyDefaultSettings() rather than reinterpret
// a Pico-era (or previous-ESP32-build) blob of a different layout.
// 17: ESP32-S3 port -- struct layout/ABI change.
// 18: added servoMaxRotationRateDegPerSec, servoAssistMarginDeg.
// 19: added otaUsername, otaPassword.
// 20: added tiltMinPulseUs, tiltMaxPulseUs, tiltCenterPulseUs,
//     tiltMinAngleDeg, tiltZeroAngleDeg, tiltMaxAngleDeg.
// 21: added servoMinAngleDeg, servoMaxAngleDeg; dropped tiltZeroAngleDeg
//     (angle 0 is fixed as the center-pulse reference for both servos now).
// 22: added panMaxSpeedDegPerSec, tiltMaxSpeedDegPerSec, cameraJoystickCurve.
// 23: added webcamAddress, webcamStreamModeMjpeg, s3camAddress (moved off
//     browser localStorage so every device sees the same camera config).
// 24: ESP32-C5 port -- struct layout/ABI can differ between xtensa-esp32s3-elf
//     and riscv32-esp-elf (padding/alignment rules aren't guaranteed
//     identical), so the first C5 boot must fall through to
//     applyDefaultSettings() rather than reinterpret an S3-era blob.
// 25: dropped webcamAddress, webcamStreamModeMjpeg -- the "IP Webcam" panel
//     (built for a phone running the IP Webcam Android app) was removed;
//     this robot only ever streams from its own S3 CAM (s3camAddress).
// 26: dropped s3camAddress -- the S3 CAM's IP never needs to be entered or
//     persisted at all: the C5 already learns it live over the UART link
//     (uart_link.cpp) the moment the cam starts sending its status line, so
//     /camdiag's own reported ip is now the sole source of truth everywhere
//     (Main page's "Open cam page" link, cam.js's stream/settings link).
// 27: added fireballSpeedMps, monsterSpeedMps, monsterCount,
//     monsterStandoffDistanceM (Camera page's fireball/monster mini-game,
//     now configurable from the Main page's "Game settings" panel instead
//     of hardcoded in cam.js).
// 28: added gameMode (select "No game"/"Monster hunt" from the Main page,
//     default "No game"); dropped monsterStandoffDistanceM, added
//     monsterLegDistanceM -- monsters no longer chase-and-hold at a fixed
//     distance from the camera, they pick a new (lightly player-biased)
//     random heading and walk it for this many meters before re-choosing,
//     so they don't park themselves in front of the player indefinitely.
constexpr uint32_t SETTINGS_VERSION = 28;
constexpr const char *NVS_NAMESPACE = "robot";
constexpr const char *NVS_KEY = "settings";

const char *TAG = "settings";

} // namespace

Settings settings;
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

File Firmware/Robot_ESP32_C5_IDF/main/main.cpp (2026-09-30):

#include "board_pins.hpp"
#include "motors.hpp"
#include "encoders.hpp"
#include "control_task.hpp"
#include "serial_console.hpp"
#include "settings.hpp"
#include "log_task.hpp"
#include "oled.hpp"
#include "watchdog.hpp"
#include "breadcrumb.hpp"
#include "diagnostics.hpp"
#include "littlefs_init.hpp"
#include "wifi_connect.hpp"
#include "web_server.hpp"
#include "ws_broadcast.hpp"
#include "uart_link.hpp"
#include "ping_diag.hpp"
#include "ota.hpp"
#include "debug_pan.hpp"

#include "esp_log.h"
#include "nvs_flash.h"

// Full feature parity with Robot_ESP32_S3_IDF: local control, WiFi/web
// server/WebSocket, the S3-CAM UART link, and now OTA -- the last piece
// deferred by the staged port plan at
// C:\Users\vince\.claude\plans\shiny-squishing-bengio.md.

extern "C" void app_main(void) {
    // Must be the very first thing app_main() does, before any other init:
    // the TB6612's AIN1-2/BIN1-2/PWMA/PWMB pins and both servo signal lines
    // float on reset (the ROM bootloader runs for a while before app_main
    // is even reached), and a floating driver/servo input is an undefined
    // output. This does not cover that ROM window itself -- only external
    // pulldowns on the pins do -- but it closes the window from here on,
    // including every future reboot.
    motors_force_safe_state();

    // Must run before control_task_start() below: the control task starts
    // writing ITS OWN fresh breadcrumbs (via breadcrumb_mark_core1()) the
    // instant it launches, well before this point would otherwise run.
    // Harmless to call this early: it only reads RTC memory, no dependency
    // on anything initialized after it.
    breadcrumb_capture_boot_snapshot();

    ESP_LOGI("main", "LynXP ESP32-C5 -- full feature parity (wifi + http + control modes + diagnostics + CAM link + OTA)");

    // Standard ESP-IDF idiom: nvs_flash_init() can report that the
    // partition's data is stale (format changed between IDF versions) or
    // that it ran out of free pages; either way, erasing and retrying once
    // is the documented recovery, not a real error path.
    esp_err_t nvsErr = nvs_flash_init();
    if (nvsErr == ESP_ERR_NVS_NO_FREE_PAGES || nvsErr == ESP_ERR_NVS_NEW_VERSION_FOUND) {
        ESP_ERROR_CHECK(nvs_flash_erase());
        nvsErr = nvs_flash_init();
    }
    ESP_ERROR_CHECK(nvsErr);

    // Try to load a previous session's settings, and only fall back to (and
    // persist) defaults if none exist yet or the version doesn't match.
    if (!loadSettings()) {
        applyDefaultSettings();
        saveSettings();
    }

    littlefs_init();
    motors_init();
    encoders_init();
    web_server_recenter_servo(); // see its own doc comment -- must run after settings are loaded, before HTTP bring-up
    log_task_start(); // before control_task_start(): controlModesTick() may submit log lines from tick 1
    control_task_start();
    serial_console_start();

    wifi_connect_start();
    uart_link_start(); // listens for the S3 CAM's periodic status line -- see board_pins.hpp's CAM_UART_* pins
    ping_diag_start(); // ICMP-pings the cam once uart_link knows its IP, for a live WiFi-quality signal
    oled_status_start(); // after wifi_connect_start(): the MAC must already be known for the first frame
    web_server_init();
    ws_broadcast_start();
    ota_register_routes();
    debug_pan_register_routes();

    // Both tasks now exist -- subscribe them to the task watchdog and start
    // measuring their tick timing/stack usage.
    watchdog_system_init(control_task_get_handle(), ws_broadcast_get_poll_task_handle());
    // Before watchdog_last_reboot_was_hang() below: it reads why the health
    // watchdog restarted the previous boot, if it did.
    watchdog_health_start(control_task_get_handle());
    diagnostics_register_tasks(ws_broadcast_get_poll_task_handle(), WS_POLL_TASK_STACK_BYTES,
                                control_task_get_handle(), CONTROL_TASK_STACK_BYTES);

    if (watchdog_last_reboot_was_hang()) {
        const BreadcrumbSnapshot &bc = breadcrumb_get_boot_snapshot();
        ESP_LOGW("main", "*** Last reboot was a hang recovery: %s ***", watchdog_last_reboot_reason_string());
        ESP_LOGW("main", "*** core0 was at: %s | core1 was at: %s (tick %lu) | last WS message: '%s' ***",
                 breadcrumb_core0_checkpoint_name(bc.core0Checkpoint),
                 breadcrumb_core1_checkpoint_name(bc.core1Checkpoint),
                 (unsigned long) bc.core1TickCountAtLastMark, bc.lastWsMessageType);
    }

    // Last: only mark this boot "known good" (cancelling the OTA rollback
    // countdown) once everything above has actually started successfully.
    ota_start_validation();
}

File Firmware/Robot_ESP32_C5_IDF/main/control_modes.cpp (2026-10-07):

#include "control_modes.hpp"

#include "settings.hpp"
#include "odometry.hpp"
#include "board_pins.hpp"
#include "control_task.hpp"
#include "breadcrumb.hpp"
#include "log_task.hpp"

#include "esp_timer.h"

#include <cmath>
#include <cstdio>
#include <algorithm>

// Ported from Robot_Pico2W_SDK/src/control_modes.cpp. Every algorithm is
// unchanged -- only the platform substitutions noted inline (millis_now(),
// the logging block's printf -> log_task_submit(), and the header set
// above) differ from the source.

float V1[2] = {0, 0};
float controlJoyX = 0;
float controlJoyY = 0;
float controlFrameThetaRad = 0.0f;
float controlFrameRotateInput = 0.0f;
volatile float aimTargetOmegaRadPerSec = 0.0f;
volatile unsigned long lastAimMsgMs = 0;
volatile float cameraRelativePanRad = 0.0f;
volatile unsigned long lastCameraRelativeMsgMs = 0;

bool cameraRelativeActive() {
    unsigned long nowMs = (unsigned long) (esp_timer_get_time() / 1000); // (millis_now(), defined further down)
    return lastCameraRelativeMsgMs != 0 && nowMs - lastCameraRelativeMsgMs < CAMERA_RELATIVE_ACTIVE_MS;
}

float goalX_m = 0.0f;
float goalY_m = 0.0f;
float goalHeadingRad = 0.0f;
bool goalHasHeading = false;
bool goalForceHeading = false; // (this goto turns to its heading whatever settings.gotoPreserveHeading says)
bool goalMaintainSpeed = false;

float wheelPosRev[2] = {0, 0};
float wheelVelRevPerSec[2] = {0, 0};
int motorPowerPwm[2] = {0, 0};

float gotoWheelVelSetpointRevPerSec[2] = {0, 0};
float gotoWheelPosSetpointRev[2] = {0, 0};
float gotoTargetHeadingRad = 0.0f;
bool gotoControllerNeedsInitFlag = false;
float gotoFfPwm[2] = {0, 0};
float gotoPPwm[2] = {0, 0};
float gotoIPwm[2] = {0, 0};
float manualVelSetpointRevPerSec[2] = {0, 0};
bool gotoDiagnosticsEnabled = false;

unsigned long lab1StartTimeMs = 0;
bool lab1Forward = true;
float lab2SetpointM[2] = {0.0, 0.0};
bool setSetpointToCurrentPosFlag = false;

bool resetEncodersFlag = false;
bool resetPoseFlag = false;
float resetPoseX_m = 0.0f;
float resetPoseY_m = 0.0f;
float resetPoseTheta_rad = 0.0f;

bool startDeadzoneCalibrationFlag = false;
bool deadzoneCalibrationActive = false;
int deadzoneCalibrationPwm = 0;
volatile bool settingsSaveRequestedFlag = false;

bool startEncoderCalibrationFlag = false;
int encoderCalibrationWheel = 0;
bool encoderCalibrationActive = false;
float encoderCalibrationRevsDone = 0.0f;

namespace {
unsigned long millis_now() { return (unsigned long) (esp_timer_get_time() / 1000); }
constexpr float GOTO_ARRIVAL_TOLERANCE_M = 0.03f;
constexpr float GOTO_HEADING_ARRIVAL_TOLERANCE_RAD = 3.0f * (float) M_PI / 180.0f; // ~3 degrees
constexpr float GOTO_HEADING_ROTATE_KP = 1.0f;
constexpr float GOTO_HEADING_ROTATE_MAX_FRACTION = 0.4f; // cap well below full speed -- final adjustment, not the main move
// Floor + tie-break for the in-place turn-toward-target branch below: as the
// target approaches directly behind the robot (180 deg off), the turn
// command's magnitude (proportional to sin of the angle) vanishes toward
// zero right as its sign becomes numerically unreliable -- without a floor,
// the robot commands an ever-shrinking turn that ends up below the motor
// deadzone and never actually turns at all.
constexpr float GOTO_INPLACE_TURN_MIN_FRACTION = 0.15f;
constexpr float GOTO_INPLACE_TURN_SIGN_DEADBAND = 0.02f;
constexpr unsigned long DEADZONE_RAMP_INTERVAL_MS = 20;
constexpr long DEADZONE_CALIBRATION_ENCODER_THRESHOLD = 20;
constexpr float ENCODER_CALIBRATION_TARGET_REVS = 10.0f;
constexpr float ENCODER_CALIBRATION_SPEED_REV_PER_SEC = 0.3f; // slow enough to count turns by eye
} // namespace

float wheelRadiusMeters() {
    return (settings.wheelDiameterMm / 1000.0f) / 2.0f;
}
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

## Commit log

2026-09-02 Add C5 robot and S3-CAM firmware to Firmware/
    Ports both projects' current firmware into this repo. Splits WiFi
    credentials out of source into gitignored wifi_creds.h files (with
    .example templates), matching the S3-CAM project's existing scheme, so
    the repo can go public without leaking network passwords. Also ports
    the S3-CAM's multi-network fallback scan (tries a priority list of
    networks, joins whichever is in range) to the C5 robot, replacing its
    single hardcoded fallback network, while keeping the C5's non-blocking
    WiFi startup so the control loop stays usable with no network at all.
    [partitions.csv]
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2026-09-24 PCB requirements: fixed 5 V servo rail, 3 A continuous
    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
2026-09-27 Add WiFi setup mode, AR games and object detection, camera OTA
    Robot (ESP32-C5):
    - Replace hardcoded wifi_creds.h with an NVS list of up to 50 networks
    (one-time migration), an open setup AP with captive DNS and a WiFi
    page to scan/add/forget/connect; optional 5 GHz preference; nearby
    scans can also be run through the S3 camera's antenna.
    - Keep the 2.4 GHz-only camera on a reachable network: only push
    credentials when it isn't already on the robot's subnet.
    - OLED: u8g2 proportional fonts with the IP in the largest fitting
    size, scrolling long lines, wrap-around fix (OFFSETX=0) and a
    one-time panel wake after a cold start.
    - Games & apps page with robot-side settings/scores (app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
    [partitions.csv]
2026-09-27 Camera view: world axes, gamepad, set-home, overlay recovery
    - World axes overlay (on by default): X red, Y green, ticks every half
    meter with white labels (half meters only where there's room), and
    X/Y letters above the +1 mark.
    - Waypoint beacons: GTA-style magenta, 75% opaque at the base; edge
    arrow for a waypoint behind the player now sits on the bottom edge.
    - Gamepad support (Gamepad API, standard layout, e.g. GameSir G8):
    sticks drive/look, A/RT/Start fire, LB/RB weapons, LT half speed;
    status line and connect toast, with a note on http-only browsers.
    - Menu: Reload page; Overlays: Set position as home (two-tap confirm).
    New /set?reset_home resets position and aligns world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
    [web_server.cpp]
2026-09-27 Keep the camera steady while the chassis turns (pan servo lead)
    Measured with new in-place turn experiments (camera heading tracked
    from the video): the pan servo was updated only every ~60 ms and lags
    its command by ~60 ms, so the camera trailed the chassis by rate x lag
    -- up to 24 deg at ~235 deg/s. The follow loop now updates every 20 ms
    (the servo's PWM frame) and aims 70 ms ahead using the chassis turn
    rate from the wheel encoders (ignored below ~6 deg/s so a still robot
    doesn't nudge the servo). Peak error at ~235 deg/s: 24 -> ~6 deg; at
    ~130 deg/s: 12 -> ~4 deg.
    debug_pan.cpp adds the experiment tooling, gated like /update:
    /debug/panexp (scripted in-place rotation or servo step wit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
    [debug_pan.cpp, main.cpp, ws_broadcast.cpp]
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2026-09-27 WIP: non-blocking WebSocket sends; drive-recording tooling
    Not yet verified in real use -- see the notes below; kept off main.
    - ws_broadcast: telemetry/pong frames are built locally and written with
    MSG_DONTWAIT, with a per-client backlog (new frames dropped while one
    is pending, client closed after 2 s without progress) instead of the
    blocking httpd_ws_send_frame_async(), which could hold the
    watchdog-monitored poll task for 3-6 s and reboot the robot (the "hang
    in pose_broadcast", e.g. on a phone page reload). httpd close_fn clears
    a closed socket's backlog. Survived a stalled WS reader + 4 bursts of
    25 parallel connections with no reboot and uninterrupted telemetry.
    Afte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
    [debug_pan.cpp, main.c, web_server.cpp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]
2026-09-27 Add David: shoot open crates for new pistols, defeat the monsters
    A new AR game (in-game texts in Dutch). Each level puts wooden crates
    on the floor around the robot; shoot them open for coins or hearts.
    The golden crate holds the next pistol -- water pistol, laser pistol,
    double pistol, lightning gun (hold to auto-fire), rainbow cannon (splash
    damage) -- which flies to the player. Slimes, bats and angry blobs crawl
    closer and cost a heart on contact; every third level adds a big boss.
    A level is done when all crates and monsters are gone.
    Settings: difficulty, hearts, play-area radius, aim assist, radar and
    edge arrows. Own high-score board. New synthesized sounds for the
    weapons, crates a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
2026-09-28 Add Temple of LynXP, a jump-and-shoot adventure with a puzzle and a boss
    A 2 x 3 m temple laid out on the floor in front of the robot, played with
    virtual jumping: a hall of spike pits and lava with stone blocks to climb
    for treasure (the ground follows platforms and drops into pits), a
    lights-out glyph floor that raises the portcullis (a glyph flips when you
    step on it -- jump over the ones you don't want), and a guardian whose
    shield drops only when its three crystals are shot (reachable mid-jump);
    jump its floor shockwaves, dodge its fireballs. Bats and scarabs harass
    you along the way. Score for treasure, kills and speed goes to the
    scoreboard; dying lets you get up where you are for 500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
2026-09-28 Temple: fewer scarabs on the glyph floor, so there's time to think
    They came every 4.5-8 s (up to 3 at once) until the puzzle was solved.
    Now a fixed number arrive (2 / 4 / 6 by difficulty), one at a time, the
    first 10 s after entering the chamber and each next one 12-25 s after
    the previous is gone.
2026-09-28 Gamepad A jumps; Temple's bats come one at a time
    Gamepad: A is jump in games with jumping (the usual layout), B still
    works too; fire moves to RT / X / Start. Where nothing can jump -- games
    without jumping, title and game-over screens -- A is fire / action as
    before. Jump listeners now report whether jumping applies right now, so
    an A press mid-air doesn't turn into a shot. Games page and setting
    labels updated.
    Temple: the hall of pits had three bats diving at you at once. Now 1 / 2
    / 3 by difficulty, one at a time (the next 5 s after the last is gone),
    each hovering 2.5-4 s where it appears before it swoops, slower (0.15
    instead of 0.22 m/s), one shot each except on hard.
    Co-Authored-B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
2026-09-29 WIP: smooth aim in games, exact draw order for blocks (untested)
    Smooth aim: while a game runs (new general setting, on by default), the
    view's heading and tilt integrate the camera turn/tilt input the page
    sends, the same way the robot does (rate x panMaxSpeedDegPerSec /
    tiltMaxSpeedDegPerSec through the joystick curve), and are pulled gently
    (0.8 s) toward the robot's own targets (controlTheta, commanded tilt),
    compared at the moment the robot computed them; big jumps snap.
    Position still comes from odometry.
    Draw order: ar.queue takes an optional axis-aligned box in a game's floor
    frame; flush() orders boxes by the plane separating them (exact for
    separate boxes) instead of by center dep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
2026-09-29 PCB requirements: name raw USB supply nets VBUS_PD and VBUS_PROG
    Avoids confusion with the V_BUS main rail.
    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
2026-09-29 OLED: show the WiFi channel and signal strength of the access point
    On networks with many access points (e.g. iotroam) it matters which one
    the robot joined and how well it hears it: one AP on a busy channel made
    the connection unstable. The network line now shows the SSID on the left
    (scrolling within the space left) and "ch40 -67dBm" on the right,
    refreshed once a second. WifiStatus gains the channel, which /wifi/status
    and the serial "wifi" command report too.
    [oled.cpp, serial_console.cpp, web_server.cpp]
2026-09-29 WiFi manager: choose a specific access point of a saved network
    Big networks (iotroam on a campus) have many access points, and the
    strongest isn't always the best: one on a crowded channel made the
    connection unstable. Scans now keep every access point (BSSID, channel,
    signal), listed per saved network under "Nearby networks" with a Use
    button. The choice is remembered (NVS) and used whenever the robot joins
    that network, falling back to any of its access points if the chosen one
    can't be reached; picking one switches over right away. The saved
    network shows which access point was chosen, with an "Automatic" button
    to go back to the strongest.
    /wifi/status adds the current BSSID, the chose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
    [web_server.cpp]
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2026-09-29 Temple: add level 2, the lower temple
    After taking the Eye of LynXP, the lower temple is laid out afresh in
    front of the robot (same 2 x 3 m footprint):
    - the dart hall: a wide spike pit with a stepping stone, a lava channel,
    and dart traps shooting low across the floor (jump them);
    - the memory floor: glyphs light up one by one, step on them in the same
    order; stepping off the floor replays it, mistakes call a scarab;
    - the obsidian guardian: four crystals, 1.3x health, rages at 75%.
    Score and time carry over; the level bonus is per level. A new
    "Start at level" setting allows starting directly at level 2.
    Claude-Session: https://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
2026-09-29 Absolute camera aim: the first-person page sends where to point
    The camera turn/tilt input used to go to the robot as rates, which the
    robot integrated for as long as it saw the key/stick held. Network jitter
    stretched or shrank short taps (sometimes to nothing), while the page's
    smooth-aim view turned the full amount and then drifted back.
    Now the page integrates the rates itself (same curve and speeds as the
    robot) and sends an absolute {"type":"aim", heading, tilt} at up to ~30 Hz
    while the aim moves; the robot sets controlFrameThetaRad and the tilt
    from it, and the servos chase them. A short tap turns the camera exactly
    as far as the view. The chassis assist (servo too slow / near its e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
    [control_modes.cpp, ws_broadcast.cpp]
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2026-09-29 Use the 8 MB PSRAM; add a health watchdog; fix the memory stats
    The robot often slowed to a crawl, the QR button stopped working, or it
    froze: internal RAM (the only heap -- PSRAM was never enabled on this
    N16R8 module) had run down to 2.2 KB free of ~190 KB. The task watchdog
    couldn't see it, since the control and poll tasks kept running.
    - PSRAM (quad, 80 MHz) enabled: malloc() spills over into it and the
    WiFi/lwIP buffers live there; boots without it if it can't start.
    Internal RAM now ~61 KB free at rest (was ~20), lowest 17.7 KB (was 2.2).
    - Health watchdog (watchdog.cpp): restarts the robot, recording why (shown
    as the last reboot reason), when internal RAM stays under 4 KB for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
    [main.cpp, oled.cpp, ws_broadcast.cpp]
2026-09-29 Camera page: floor grid/axes lines no longer vanish near the robot
    Each projected floor line was trimmed to the picture by clipping the
    straight chord between its two projected END points -- but the lens
    bends floor lines (strongly near the camera and far to the side), so for
    a long line like a world axis that chord could run above or beside the
    picture while the line itself crossed it. The line was then skipped,
    most often close to the robot with the camera tilted up, and grew back
    in from one side as the robot moved. The pieces were also evenly spaced
    along the floor (at most 48), so near the camera one piece could span a
    metre and cut across the true curve.
    Now each line is split in half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
2026-09-30 Temple: textured stone walls and floors
    ar.js generates stone textures once (sandstone and crypt blocks in courses
    with recessed mortar, relief, mottling, cracks, grain and grime; flagstones)
    and draws texture pieces on world quads as affinely mapped triangles. The
    Temple maps them onto every wall face in world-fixed tiles, cut finer close
    up, shaded by the way the face looks and hazier with distance; the sanctum's
    upper floor and block tops get flagstones. A "Textured stone" setting
    turns it off on a slow phone.
    ar.flush now only orders boxes whose screen rectangles overlap (for frames
    that can place their boxes in the world): ordering boxes that don't overlap
    could chain into a cycle that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
2026-09-30 Harden OTA auth, uploads and settings input
    - /params no longer returns the OTA password (only otaPasswordSet);
    changing the OTA username/password via /set needs the current
    credentials. The Main page gets a "New password" field and a save button.
    - The camera's /update is guarded by the same credentials, pushed to it
    over the UART link ("OTA user=<hex> pass=<hex>") and kept in its NVS.
    - Constant-time credential comparison on robot and camera.
    - Every POST body read gives up after a few receive timeouts instead of
    retrying forever (web_server_recv), so a stalled upload can no longer
    leave the robot paused and the httpd task blocked.
    - /set rejects non-numeric/NaN input and clamps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
    [main.c, ota.cpp, settings.cpp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]
2026-09-30 Temple: straight-line projection, smooth stairs, wisps, levels 2/3 swapped
    - ar.js projects game geometry with a plain pinhole (focal length from
    the lens calibration's center) instead of the barrel-distortion model,
    which folded points far off-axis back toward the center and made faces
    close to the player vanish. cam.js's floor grid and coordinate frame
    keep the lens correction so they still line up with the video.
    - The sanctum's stairs are a smooth slope for the player's height (the
    steps are still drawn as blocks); ar.js follows small drops in the
    ground instead of starting a fall, so walking down is smooth too.
    - New enemy, the wisp: darts sideways fast (0.55 m/s, direction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
2026-09-30 Temple: levels 7 (hall of mirrors) and 8 (watchers' vault)
    Level 7, game_temple_mirrors.js: sunbeams run low over the floor through
    three halls. Shoot mirrors and prisms to turn them and bend the beams onto
    crystals: gold ones keep their door open, blue ones only while lit (both at
    once for the court's door). Beams burn -- jump them; the robot's body and
    mummies block them. With the Sun Shield the robot itself is a mirror: it
    bends a beam the way it faces. Taking the Sun Disc cracks the shield and
    sets the mirrors spinning on their own for the escape.
    Level 8, game_temple_vault.js: a stealth level. Stone eyes in the walls
    sweep a visible gaze (walls and pillars block it); a sentinel walks i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
2026-09-30 Web image updates compressed: /update-fs?format=zlib (45 s -> ~6 s)
    With storage at ~12 MB, every web update uploaded and rewrote 12 MB
    (~45-57 s), though the image is mostly empty blocks. Now the image goes
    zlib-compressed (~260 KB) and the robot inflates it with the ROM's tinfl,
    twice: pass 1 checks it (LittleFS magic, fits the partition, zlib
    checksum) with nothing touched; pass 2 reads each 4 KB sector and only
    erases/writes the ones that differ. The result is the image byte for
    byte (verified with esptool verify-flash) -- unlike skipping empty
    blocks, which could leave an old LittleFS metadata block behind.
    The idle task is taken off the task watchdog for the duration (and put
    back): w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
    [ota.cpp]
2026-09-30 Temple polish: textures, doors, area colors, trampoline, columns; true-direction edge arrows
    Edge arrows (ar.js, all games): point the way the object actually lies in
    the image plane (at eye level to the left: left, not up-left), sit on the
    edge of the whole screen rather than the letterboxed video, and something
    behind you says turn left/right instead of "over the top".
    Temple of LynXP, from play-testing feedback:
    - Flat surfaces: see-through detail textures (slab joints, wear, cracks;
    marble veins on the sky citadel) over any flat color -- platform and
    block tops, and lightly over every level's floor, which stays
    see-through for AR. Floor tiles are 0.3 m, quartered only close by.
    -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
2026-09-30 Temple: cistern lift starts up, slower + realistic flames, no seeing through walls, textured platform sides
    Level 6 (the drowned cistern):
    - The lift starts up, level with the antechamber floor over the shaft --
    you ride it down instead of meeting a black hole. On the way down the
    shaft is drawn (stone walls, the lift inside it) from above and from in
    it. The fall checks no longer fire during a ride (they teleported you
    half-way, then reset your height near the bottom).
    - Flame vents cycle in 3.8 s instead of 3.0 (same 1.2 s burst); the timed
    gate gets 2 s more to make up for the waiting.
    - Flames: swaying teardrop tongues (white core, orange, red), flaring up
    and dying down, a g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
2026-10-01 Knight on Blocks: the Pocket Knight climbs real 40 mm blocks found by their AprilTags
    Real blocks (40 mm cubes, 30 mm tag36h11 tags on one or more faces) are
    found by the camera and mapped in the odometry frame (tagblocks.js):
    frames from the camera stream go to a Web Worker (apriltag_worker.js) that
    runs the AprilTag C library compiled to WebAssembly (arenaxr/apriltag-js-
    standalone, BSD-3), loaded from jsDelivr at a pinned commit. Each tag's
    corners are undistorted with the lens calibration, its pose comes from a
    homography, and the camera pose of the shown frame puts it in the world.
    A tag on a top or side face gives the block's center and heading (mod 90
    deg), its height snapped to stack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
2026-10-01 Knight on Blocks: 30 mm blocks / 22.5 mm tags, the robot's real footprint
    - Defaults now 30 mm cubes with 22.5 mm tags (the user's blocks), also on
    the printable sheet; the detector runs at full resolution (37 ms/frame
    in the mock) for the smaller tags' corners and range.
    - The keep-out is the robot's footprint, not a circle round the odometry
    point: half-width to each side and in front of the drive wheels' axle,
    and back to the caster (18 cm behind it, a new setting), oriented by the
    chassis heading (from the robot's pose telemetry). A move is checked over
    goto's turn on the spot (toward the target or, reversing, away) and the
    straight drive after it; detours the same way; a r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
2026-10-01 Knight on Blocks: tag16h5 (the user's AprilTagDetector build), 19 cm robot
    - Tags are tag16h5 by default (the user's blocks: the same tag on all six
    faces). Detector: vgroenhuis/AprilTagDetector -- the AprilTag C library
    for tag16h5 in WebAssembly, with each detection's bit errors and decision
    margin -- from jsDelivr at a pinned commit; tag36h11 stays available
    (arenaxr build), a "Tag family" setting. tag_worker.js replaces
    apriltag_worker.js; like AprilTagDetector it keeps only exact codes with a
    decision margin of 25+, at least 10 px a side, roughly square.
    Synthetic 30 mm cubes with tags on every face: 3-4 mm, ~1-4 deg near; two
    faces of one block in one frame make one blo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
2026-10-01 Knight on Blocks: a 3 cm knight, walking at its own scale
    The Pocket Knight's 7 cm body towered over the 30 mm blocks. Here it's
    3 cm by default (a "Knight's height" setting): its lengths, speeds and
    gravity scale with it (time doesn't), so it walks and runs like a person
    its size (~7.7 cm/s running); drawn at that size, limbs included. Its jump
    is a bit heroic (60% of its height) -- enough to vault onto a block as tall
    as itself; stacks go a block at a time. The animation gets its speeds in
    Pocket Knight units, so the gait still matches the ground speed.
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2026-10-01 Knight on Blocks: blocks at the height they're seen, not snapped to the floor
    The camera's height/tilt calibration needn't be perfect: a block snapped
    onto the floor then didn't line up with the video. Each block now keeps
    its observed center height (averaged like its position); the stacking
    level still comes from the nearest multiple of the block size (grouping,
    inferred supports -- these now sit a block below the one above). Tested
    with the camera 1 cm higher than calibrated: blocks seen ~1 cm low, levels
    right.
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2026-10-02 Knight on Blocks: no start scan, calmer robot and camera, same-tag cubes
    - Starts with the blocks in view; looking around first is now an opt-in setting.
    - The robot's goto spot glides at <= 5 cm/s with a 1.5 cm deadband; the camera
    eases toward the knight and pans at <= 0.5 rad/s (less lag misalignment, no jitter).
    - Sightings join the nearest block by position, not by tag id, so several cubes
    may share a tag (a same-tag stack no longer flips one block between levels).
    - One clear sighting of one face makes a block; faint ones still need two.
    - Tags seen more than 60 degrees off-axis are skipped (their poses are unreliable).
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2026-10-02 Robot-frame camera: ease to the stick's angle at limited rates; panic handler in IRAM
    Three freezes with only the servos moving in the robot-frame mode: CPU
    lockup in the panic handler, then 'SPI flash busy' boot loops until a power
    cycle -- the flash stopped answering. The absolute stick mapping made both
    servos jump at full speed at once (the default mode moves them at a rate),
    the likely supply dip. Now the commanded pan/tilt move toward the stick at
    180 / 120 deg/s (the default mode's rates), starting from the servos'
    reported angles, and the pan stops at +-80 deg.
    CONFIG_ESP_PANIC_HANDLER_IRAM: the panic handler no longer needs the flash,
    so if it happens again it can still report what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
2026-10-02 Robot-frame camera: the robot eases the servos itself, every 20 ms
    The page sent eased setpoints at 25 Hz and the tilt servo jumped to each on
    arrival: ~5 deg steps, bunched by WiFi -- visibly jittery. Now the page sends
    the stick's target and the servo-follow tick moves pan and tilt toward it
    every 20 ms at panMaxSpeedDegPerSec / tiltMaxSpeedDegPerSec, from where they
    are. The page's own eased copy (for the view) takes its rates from /params.
    [ws_broadcast.cpp]
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2026-10-03 Robot drive mode: no dead zone on the camera stick (it sets an angle, noise can't drift)
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2026-10-05 Free drive cube detection, Tags page, remembered tag sizes, world frame from a cube
    - Free drive: Overlays switches for AprilTag cube detection, cube outlines,
    tag outlines and 'World frame from cube' (freedrive_tags.js, the same block
    map as Knight on Blocks).
    - Frame cube: tags 24 +X, 25 +Y, 26 +Z, 27 -X, 28 -Y, 29 -Z, 40 mm by
    default. Seen steadily, the world origin goes to its center on the floor
    and +X along tag 24's facing: the robot's pose is set to match via the new
    /set?set_pose (the robot doesn't move, the world does), and the map moves
    along. Side tags give the heading.
    - Tag sizes, cube counts and last-seen places are remembered on the robot
    (new appdata document '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
    [web_server.cpp]
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2026-10-07 Camera calibration in steps: lens, servos, mount
    The all-in-one extrinsics fit let errors leak into the servo gains (a
    saved result turned a commanded 90 deg into 85). Calibration now goes in
    three steps (the app's "Calibrate" setting):
    2. Servos (new, app_camservo.js + camservo.js): in front of the
    checkerboard the robot drives 25 cm back and forth at pan 0 (the
    board's middle in the camera's frame vs the odometry path gives where
    straight ahead really is), turns on the spot by -c while the pan servo
    is told +c (c = 30, 60, 90 each way: the camera's yaw change to the
    board less the chassis's turn is the servo's real angle), and tilts up
    and down. New pan min/center/max an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
    [control_modes.cpp, ws_broadcast.cpp]
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
